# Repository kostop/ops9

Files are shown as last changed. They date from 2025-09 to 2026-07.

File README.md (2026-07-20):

# OPS9 全局定位模块

基于 STM32F103C8 的全局定位模块控制工程。主控通过两路编码器和 IMU 获取运动状态，计算底盘平面位置与航向角，并通过串口向外部控制器发送定位反馈数据。

## 项目内容

| 路径 | 说明 |
| --- | --- |
| `code/` | STM32CubeMX 工程、应用代码、HAL 驱动和 Keil MDK 工程 |
| `code/MDK-ARM/ops9.uvprojx` | Keil uVision 主工程 |
| `pcb/OPS9.epro` | 主板 PCB 工程 |
| `model/` | 机械总装配模型、STL 文件和打印示例 |
| `example/` | 样例底盘的 STM32、PCB、模型与 HMI 工程 |
| `全局定位模块材料清单.xlsx` | 主模块物料清单 |

## 硬件与外设

- MCU：STM32F103C8，外部晶振经 PLL 配置为 72 MHz。
- 两路编码器：TIM1 / PA8、TIM2 / PA0，用于读取两侧轮速和累计脉冲。
- IMU：USART1，115200 bps，PB6 为 TX、PB7 为 RX；使用 DMA 空闲接收。
- 外部通信：USART2，115200 bps，PA2 为 TX、PA3 为 RX；使用中断收发。
- I2C：I2C1，PB8 为 SCL、PB9 为 SDA。
- 状态指示灯：PC13。

## 软件功能

- 读取两路编码器脉冲，计算角速度、轮速和累计里程。
- 接收 IMU 偏航角，处理跨越 `-PI` / `PI` 的航向累计。
- 根据当前行进方向将轮速积分为平面位置 `x`、`y` 和航向 `z`。
- 周期性通过 USART2 上报定位数据；发送帧以 `0x5C` 开头，包含 `x`、`y`、`z` 和 CRC8。
- 接收外部控制命令；收到 `0x22` 时会复位 MCU。

## 编译与下载

1. 安装 Keil MDK-ARM，并添加 STM32F1 设备包。
2. 使用 Keil uVision 打开 `code/MDK-ARM/ops9.uvprojx`。
3. 按实际硬件确认 `code/ops9.ioc` 中的时钟、引脚和串口配置；如使用 STM32CubeMX 重新生成代码，需保留各文件的 `USER CODE` 区域。
4. 在 Keil 中选择 `ops9` 目标，执行 Build。
5. 使用 ST-Link 或兼容 SWD 调试器下载生成的固件。

## 串口使用注意事项

当前工程的 USART1 和 USART2 都按全双工异步串口配置。若硬件改为单线、RS-485 无自动方向控制，或让一条线在收发之间切换，则属于半双工通信，必须重新设计串口收发流程。

> **高风险：半双工场景下，在发送未完成时重新启动接收，或在接收回调中直接发起发送，可能使 HAL 的 `gState` / `RxState` 长期保持 `HAL_UART_STATE_BUSY_*`。后续 `HAL_UART_Transmit_*` 或 `HAL_UART_Receive_*` 会持续返回 `HAL_BUSY`，表现为串口“锁死”。**

- 同一 UART 同一时刻只允许一个收发事务。发送前检查状态或维护独立的软件状态机；不要像当前 `Robot_com_send_data()` 一样无条件高频调用 `HAL_UART_Transmit_IT()` 后又假定已经发送成功。
- 半双工方向应由明确的状态机控制：停止接收 -> 切换为发送方向 -> 启动发送 -> 在 `HAL_UART_TxCpltCallback()` 中确认发送完成 -> 切换为接收方向 -> 重新启动接收。
- 不要在 `HAL_UART_RxCpltCallback()`、`HAL_UARTEx_RxEventCallback()` 等中断回调中使用阻塞式 `HAL_UART_Transmit()`、延时函数或复杂业务逻辑。回调只记录事件、复制数据或投递标志，实际发送放到主循环或任务中处理。
- 必须检查每次 HAL 串口调用的返回值。发生 `HAL_BUSY`、超时、帧错误、噪声错误或溢出错误时，先停止当前事务并清理错误标志，再按统一的恢复流程重新初始化或重新启动接收。
- 若使用 RS-485 收发器，DE/RE 的时序应覆盖整个发送过程，并以发送完成回调为准释放总线；不能仅依据写入发送寄存器就立即切换方向。
- DMA 接收缓冲区在重新启动 `HAL_UARTEx_ReceiveToIdle_DMA()` 前不得被其他上下文修改。正常模式 DMA 完成或空闲事件后，应只重新启动一次，避免中断和主循环并发重复启动。
- 为串口事务设置合理超时和错误计数；连续异常时执行受控恢复。恢复失败后再由看门狗或上层策略复位，避免在中断中无限重试。

推荐的半双工流程如下：

```text
空闲/接收 -> 收到完整请求 -> 停止接收并切换 TX 方向
          -> 启动发送 -> Tx 完成回调 -> 切换 RX 方向 -> 重启接收
```

## 开发约定

- 修改 STM32CubeMX 自动生成文件时，仅在 `USER CODE BEGIN` / `USER CODE END` 区域编写用户代码。
- 业务状态、通信参数较多时使用结构体集中管理，避免分散的大量全局变量。
- 新增嵌入式函数时为函数参数补充简洁的中文注释，并保持中断服务函数短小、可预测。
- 提交前应至少验证：编码器方向、IMU 航向零点、串口帧格式、CRC8 校验和异常恢复流程。

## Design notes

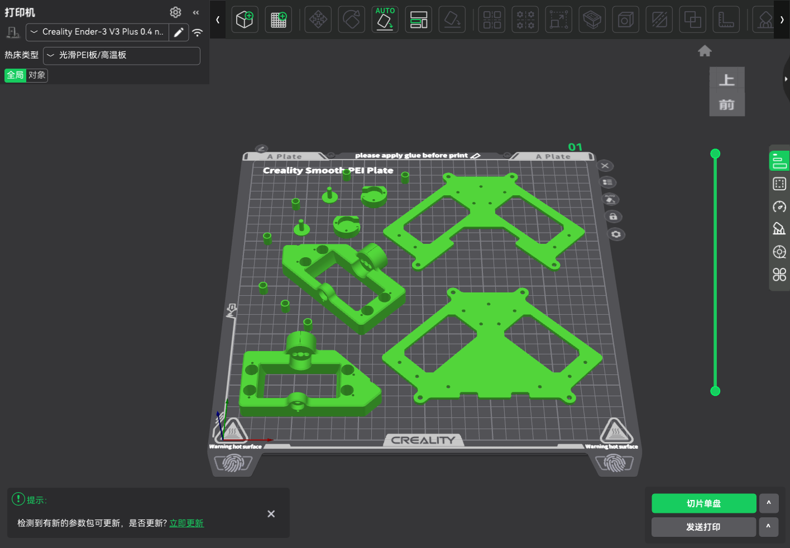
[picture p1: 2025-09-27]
model/打印示例.png

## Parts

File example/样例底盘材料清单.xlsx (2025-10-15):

底盘
序号 | 材料 | 数量 | 单价 | 总价 | 链接（仅作参考） | 备注
 | 底盘电机驱动 | 4 | 49.99 | 199.96 | https://item.taobao.com/item.htm?id=635439412574 | Emm28_V5.0 PLC套餐
 | 电机支架 | 4 | 2.2 | 8.8 | https://item.taobao.com/item.htm?id=580451007567 | 42步进电机支架
 | 底盘电机 | 4 | 19.38 | 77.52 | https://item.taobao.com/item.htm?id=649664531631 | 42电机/高40mm带1000mm杜邦线[D款]
 | OPS9 | 1 |  | 0 |  | OPS9和底盘固定的位置需要添加12mm的打印件垫高（见模型
 | 麦轮 | 1 | 182.8 | 182.8 | https://item.taobao.com/item.htm?id=636447218110 | 75mm（4只麦轮）;5mm;铝套版 这个轮子其实不是很好用，但是便宜，可以自己挑好一点的
 | 板材 | 1 | 100 | 100 | https://item.taobao.com/item.htm?id=738518121036&sku_properties=31309%3A33722 | 见模型
 | 底盘控制板ZET6 | 1 | 110 | 110 | https://detail.tmall.com/item.htm?id=609293737870 | 不焊排针(带SRAM) 可以换其他的控制板，便宜点的
 | 电池 | 1 | 33 | 33 | https://item.taobao.com/item.htm?id=640509882798 | 12V一字型【3000mAh】
 | 电源开关 | 1 | 1.98 | 1.98 | https://detail.tmall.com/item.htm?id=18691413288 | 开孔20mm 全圆实心红色不带灯2档3脚 6A 250V 铜脚 （2个）
 | 降压模块 | 1 | 4.7 | 4.7 | https://item.taobao.com/item.htm?id=522572489248 | 3A超小模块/固定输出5V/D-SUN
 | 铜柱 | 4 | 3.46 | 13.84 | https://detail.tmall.com/item.htm?id=601483145867 | M4*40【5个】
 | GH1.25 | 1 | 0.68 | 0.68 | https://item.taobao.com/item.htm?id=709930896705 | 4P;300MM;杜邦2.54母-1P;GH1.25
 | XT30 | 8 | 1.04 | 8.32 | https://item.taobao.com/item.htm?id=577565809725 | XT30U-F母头 XT30U-M公头 各四个
遥控器
序号 | 材料 | 数量 | 单价 | 总价 | 链接（仅作参考） | 备注
 | 串口屏 | 1 | 103 | 103 | https://item.taobao.com/item.htm?id=583712885361 | 电容触摸模块
 | 无线串口 | 1 | 4.9 | 4.9 | https://item.taobao.com/item.htm?id=630394357164 | L24S[价格];价格
 | 充电模块 | 1 | 2 | 2 | https://item.taobao.com/item.htm?id=962468583902 | 5V/2A充放电模块_Type-C_配USB口
 | 遥控器电池 | 1 | 11.5 | 11.5 | https://detail.tmall.com/item.htm?id=799461424541 | 804050-2000毫安

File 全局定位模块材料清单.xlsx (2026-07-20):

个人方案（并非价格最低，可以根据备注更改方案）
序号 | 材料 | 数量 | 单价 | 总价 | 链接（仅作参考） | 备注
1 | 3D打印耗材PLA | 1 | 71 | 71
2 | 编码器 | 2 | 106 | 212 | https://item.taobao.com/item.htm?id=625215461363 | 1024线 带方向，精度要求不高可以选用256线
3 | 全向轮 | 2 | 30.6 | 61.2 | https://detail.tmall.com/item.htm?from=cart&id=756995416829&skuId=5835440637774&upStreamPrice=3060 | 3mm联轴器
4 | 陀螺仪 | 1 | 337 | 337 | https://item.taobao.com/item.htm?id=587961204951 | 裸片，可以根据需求换更便宜的，但是要注意引脚定义，我这里需求是精度高，所以直接选用这一款了
5 | 铝柱 | 8 | 0.68 | 5.44 | https://item.taobao.com/item.htm?id=775573343427 | M3*35 注意铝柱因为存在公差，最好买同款，但是并非最优的，因为这家铝柱有刷漆，所以需要装上之后去磨合一下 | https://item.taobao.com/item.htm?id=965743472192&xxc=shop&skuId=5438154337255 | 铝柱M3*35亮银本色 群友推荐铝柱
6 | 铝柱 | 4 | 3.8 | 15.2 | https://detail.tmall.com/item.htm?id=719155904600 | M4*35
7 | mcu控制器 | 1 | 9.5 | 9.5 | https://item.taobao.com/item.htm?id=679227834271 | c8t6版型都一样的都可以
8 | 直线轴承 | 8 | 2.8 | 22.4 | https://detail.tmall.com/item.htm?id=598752895908&sku_properties=122276018%3A20213 | LM5UU 5*10*15
9 | 深沟球 | 2 | 0.6 | 1.2 | https://item.taobao.com/item.htm?id=627322360377 | MR104ZZ 4*10*4mm
10 | 推力滚针 | 5 | 0.2 | 1 | https://detail.tmall.com/item.htm?id=717424513282 | 全钢0414+2AS
11 | gh1.25母座 | 1 | 0.1 | 0.1 | https://item.taobao.com/item.htm?id=622151561707 | 立卧都可以看自己需求
12 | 平头螺钉 | 3 | 4 | 12 | https://detail.tmall.com/item.htm?id=624733978863 | M4*20 M3*8 M2*10 M2*6
13 | 弹簧 | 10 | 0.4 | 4 | https://detail.tmall.com/item.htm?id=575363698316
14 | 2.54排母 | 6 | 0.5 | 3 | https://item.taobao.com/item.htm?id=668600526597 | 20P，长了直接剪刀剪了就好了
15 | 2.54排针 | 6 | 0.43 | 2.58 | https://item.taobao.com/item.htm?id=656495617585 | 单排1X40P，长了也是剪了就好了
以下部分可以看需求考虑（直接用串口供电则不需要）
16 | 降压 | 1 | 3.9 | 3.9 | https://item.taobao.com/item.htm?id=522572489248 | 3A超小模块/固定输出5V/D-SUN
17 | xt30 | 1 | 1.55 | 1.55 | https://item.taobao.com/item.htm?from=cart&id=614438530441&skuId=5691715989849&upStreamPrice=155 | XT30PW-M卧式焊板(公头）
 |  |  |  | 760.49

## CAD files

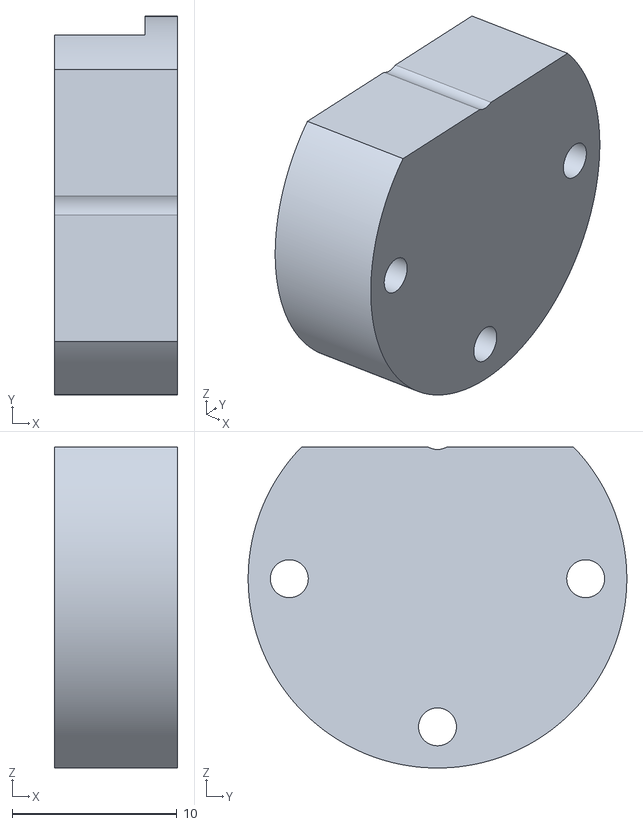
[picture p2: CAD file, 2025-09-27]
model/STL/总装配 - 编码器盖子-3.STL
7.50 x 23.0 x 19.5

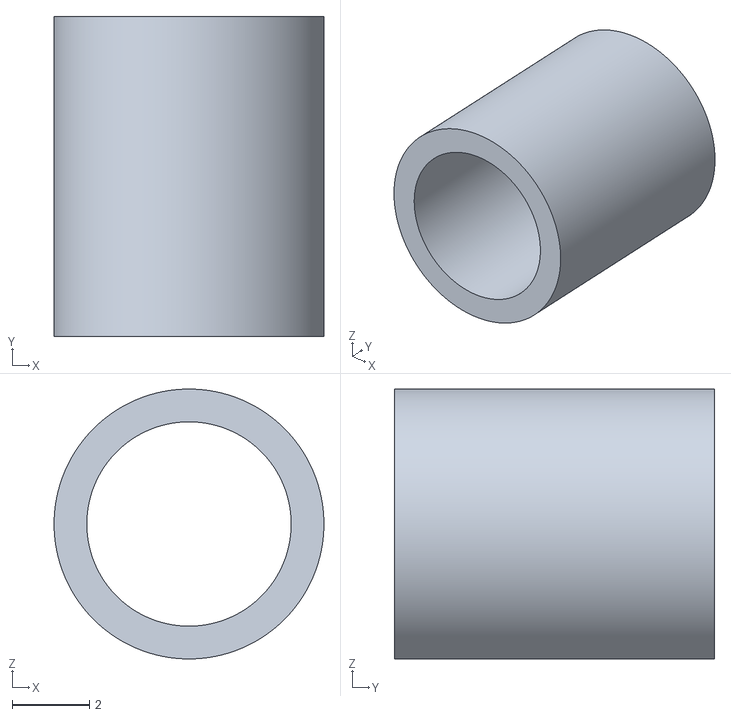
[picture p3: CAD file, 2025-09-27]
model/STL/总装配 - M5 7.5-5.STL
7.00 x 8.30 x 7.00

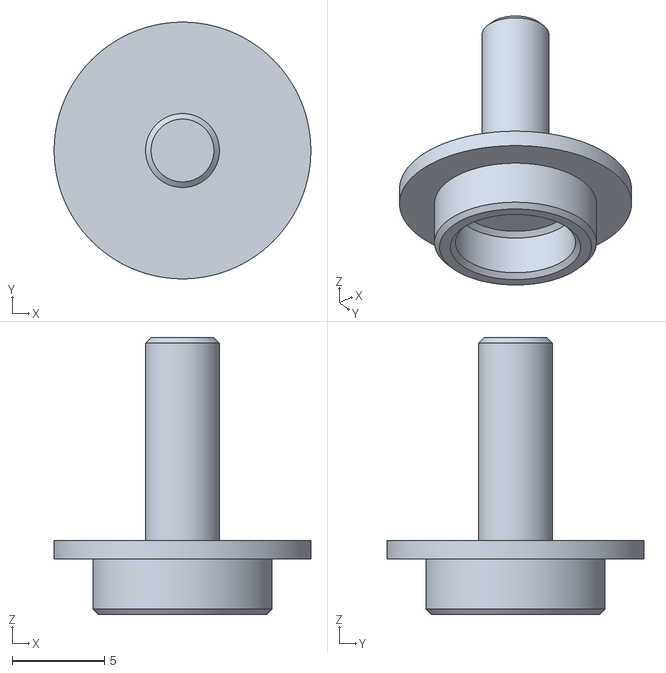
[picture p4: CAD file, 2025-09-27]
model/STL/总装配 - 全向轮轴系固定座-2.STL
13.9 x 13.9 x 15.0

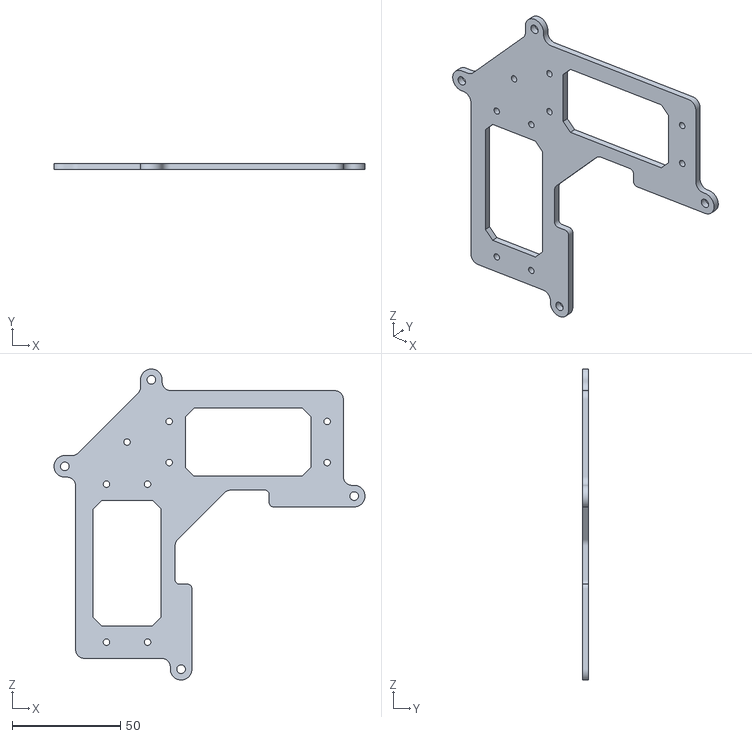
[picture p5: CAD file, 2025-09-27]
model/STL/总装配 - 底板-1.STL
143.7 x 3.00 x 143.7

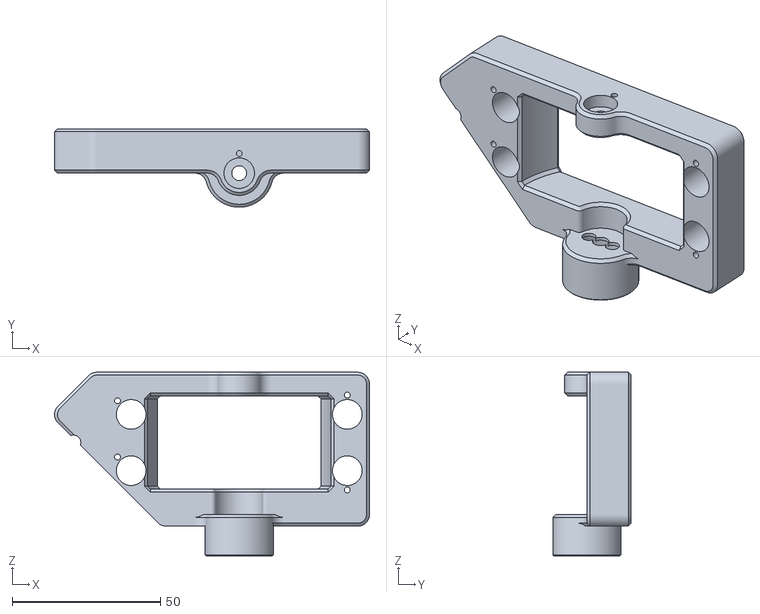
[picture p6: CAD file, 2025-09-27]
model/STL/总装配 - 编码器固定1-1.STL
106.4 x 26.5 x 62.0

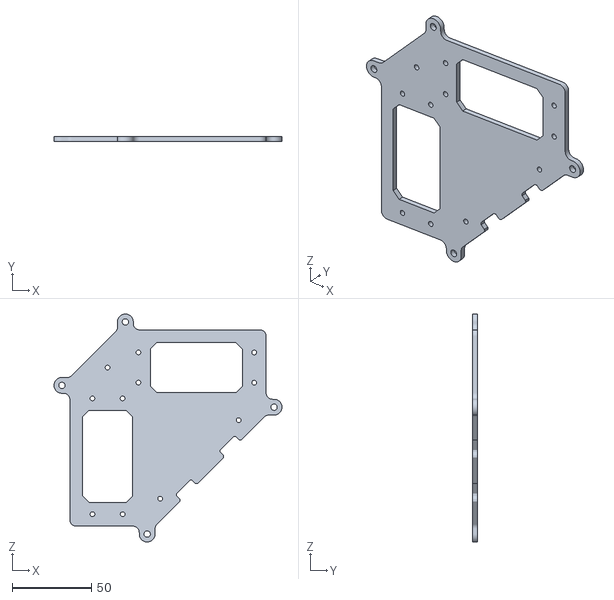
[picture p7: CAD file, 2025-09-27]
model/STL/总装配 - 顶板-1.STL
143.7 x 3.00 x 143.7

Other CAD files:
model/STL/总装配 - M5 7.5-3.STL
model/STL/总装配 - M5 7.5-6.STL
model/STL/总装配 - 全向轮轴系固定座-1.STL
model/STL/总装配 - M5 7.5-7.STL
model/STL/总装配 - M5 7.5-4.STL
model/STL/总装配 - M5 7.5-1.STL
model/STL/总装配 - 编码器固定2-3.STL
model/STL/总装配 - 编码器盖子2-1.STL
model/STL/总装配 - M5 7.5-2.STL

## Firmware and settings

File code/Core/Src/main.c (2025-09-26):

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
/* Includes ------------------------------------------------------------------*/
#include "main.h"
#include "dma.h"
#include "i2c.h"
#include "tim.h"
#include "usart.h"
#include "gpio.h"

/* USER CODE BEGIN Includes */
#include "encoder.h"
#include "delay.h"
#include "imu.h"
#include "ops9_control.h"
#include "robot_com.h"
/* USER CODE END Includes */

/* USER CODE BEGIN PD */
#define LED_DELAY		1000		//ms
#define TASK_TIME_OUT	1
/* USER CODE END PD */


/* USER CODE BEGIN PV */
uint16_t led_delay;
uint8_t get_yaw_state;
uint8_t ops9_dirt;
/* USER CODE END PV */

void SystemClock_Config(void);
/* USER CODE BEGIN PFP */
static void LED_task(uint32_t delay);
/* USER CODE END PFP */

/**
  * @brief  The application entry point.
  * @retval int
  */
int main(void)
{

  /* MCU Configuration--------------------------------------------------------*/

  /* Reset of all peripherals, Initializes the Flash interface and the Systick. */
  HAL_Init();

  /* Configure the system clock */
  SystemClock_Config();

  /* Initialize all configured peripherals */
  MX_GPIO_Init();
  MX_DMA_Init();
  MX_I2C1_Init();
  MX_TIM1_Init();
  MX_TIM2_Init();
  MX_USART1_UART_Init();
  MX_USART2_UART_Init();
  MX_TIM3_Init();
  /* USER CODE BEGIN 2 */
  delay_init();
  Encoder_init();
  IMU_init();
  Robot_com_init();
  Control_init(TASK_TIME_OUT);
  /* USER CODE END 2 */

  /* Infinite loop */
  /* USER CODE BEGIN WHILE */
  while (1)
  {
	LED_task(LED_DELAY);
	Encoder_task();
	Robot_com_send_data();
	Control_task(ops9_dirt);
	IMU_check_task();
	delay_ms(TASK_TIME_OUT);
	switch(get_ops_cmd_data())
	{
		case 0x22:
			NVIC_SystemReset();
			break;
		default:
			ops9_dirt = get_ops_cmd_data()-0x30;
			
	}
    /* USER CODE END WHILE */

    /* USER CODE BEGIN 3 */
  }
  /* USER CODE END 3 */
}

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
/* USER CODE BEGIN 4 */
void LED_task(uint32_t delay)
{
	static uint32_t led_delay =0;
	led_delay ++;
	if(led_delay >= delay)
	{
		HAL_GPIO_TogglePin(GPIOC, GPIO_PIN_13);
		led_delay =0;
	}
}

void HAL_UART_RxCpltCallback(UART_HandleTypeDef *huart)
{
	if(huart->Instance == USART2)
	{
		Robot_com_call_back();
	}
}

/* USER CODE END 4 */
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


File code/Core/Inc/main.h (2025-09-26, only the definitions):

#define LED0_Pin GPIO_PIN_13
#define LED0_GPIO_Port GPIOC
#define STEP2_Pin GPIO_PIN_0
#define STEP2_GPIO_Port GPIOA
#define STEP_ZERO1_Pin GPIO_PIN_14
#define STEP_ZERO1_GPIO_Port GPIOB
#define STEP_ZERO2_Pin GPIO_PIN_15
#define STEP_ZERO2_GPIO_Port GPIOB
#define STEP1_Pin GPIO_PIN_8
#define STEP1_GPIO_Port GPIOA
#define DIRT1_Pin GPIO_PIN_10
#define DIRT1_GPIO_Port GPIOA
#define DIRT1A11_Pin GPIO_PIN_11
#define DIRT1A11_GPIO_Port GPIOA
#define ANGLE_ZERO_Pin GPIO_PIN_5
#define ANGLE_ZERO_GPIO_Port GPIOB
#define USART_IMU_TX_Pin GPIO_PIN_6
#define USART_IMU_TX_GPIO_Port GPIOB
#define USART_IMU_RX_Pin GPIO_PIN_7
#define USART_IMU_RX_GPIO_Port GPIOB
#define IMU_SCL_Pin GPIO_PIN_8
#define IMU_SCL_GPIO_Port GPIOB
#define IMU_SDA_Pin GPIO_PIN_9
#define IMU_SDA_GPIO_Port GPIOB

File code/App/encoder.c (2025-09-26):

#include "encoder.h"
#include "tim.h"

#define ENCODER_PULSE			1024.0f
#define ENCODER_TASK_TIME_OUT	0.001f		//s


encoder_para_t encoder_para[2];

void Encoder_init(void)
{
	HAL_TIM_Encoder_Start(&htim1, TIM_CHANNEL_1);
	HAL_TIM_Encoder_Start(&htim2, TIM_CHANNEL_1);
}

void Encoder_task(void)
{
	encoder_para[0].dirt = HAL_GPIO_ReadPin(GPIOA, GPIO_PIN_10)*2-1;
	encoder_para[0].count = __HAL_TIM_GetCounter(&htim1)*encoder_para[0].dirt;
	__HAL_TIM_SetCounter(&htim1, 0);
	encoder_para[0].rate = (float)encoder_para[0].count/ENCODER_PULSE/ENCODER_TASK_TIME_OUT*2*PI;
	encoder_para[0].total_count += encoder_para[0].count;
	
	encoder_para[1].dirt = HAL_GPIO_ReadPin(GPIOA, GPIO_PIN_11)*2-1;
	encoder_para[1].count = __HAL_TIM_GetCounter(&htim2)*encoder_para[1].dirt;
	__HAL_TIM_SetCounter(&htim2, 0);
	encoder_para[1].rate = (float)encoder_para[1].count/ENCODER_PULSE/ENCODER_TASK_TIME_OUT*2*PI;
	encoder_para[1].total_count += encoder_para[1].count;
}

const encoder_para_t *get_encoder_para_point(uint8_t num)
{
	return &encoder_para[num];
}

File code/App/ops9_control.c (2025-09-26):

#include "ops9_control.h"
#include <math.h>

#define WHEEL_RADIUS			0.029f		//m
uint8_t ops9_direction = 0;

float Control_task_time_out;

control_para_t control_para;

static void feed_back(control_para_t *feed_back_point);
static void control_loop(control_para_t *control_loop_point);

float yaw_add_count(float yaw)
{
	static float yaw_last, yaw_add;
	float yaw_result;
	if(yaw - yaw_last < -PI)
		yaw_add += 2*PI;
	else if(yaw - yaw_last > PI)
		yaw_add -= 2*PI;
	
	yaw_last = yaw;
	yaw_result = yaw + yaw_add;
	return yaw_result;
}

void Control_init(uint16_t Task_time_out)
{
	ops9_direction = 2;
	for(int i=0; i<2; i++)
		control_para.control_encoder_point[i] = get_encoder_para_point(i);
	control_para.control_imu_point = get_imu_para_point();
	Control_task_time_out = 0.001f;
}

void Control_task(uint8_t dirt)
{
//	ops9_direction = dirt;
	feed_back(&control_para);
	control_loop(&control_para);
}

static void feed_back(control_para_t *feed_back_point)
{
	for(int i=0; i<2; i++)
	{
		feed_back_point->wheel_para[i].angle = (float)feed_back_point->control_encoder_point[i]->total_count/1024*2*PI;
		feed_back_point->wheel_para[i].len = feed_back_point->wheel_para[i].angle*WHEEL_RADIUS;
		feed_back_point->wheel_para[i].rate = feed_back_point->control_encoder_point[i]->rate;
		feed_back_point->wheel_para[i].speed = feed_back_point->wheel_para[i].rate*WHEEL_RADIUS;
	}

	feed_back_point->chassis_pos.z = yaw_add_count(feed_back_point->control_imu_point->yaw);
}

static void control_loop(control_para_t *control_loop_point)
{
	switch(ops9_direction)
	{
		case 0:
			control_loop_point->chassis_line.y = control_loop_point->wheel_para[0].speed*Control_task_time_out;
			control_loop_point->chassis_line.x = -control_loop_point->wheel_para[1].speed*Control_task_time_out;
			break;
		case 1:
			control_loop_point->chassis_line.x = control_loop_point->wheel_para[0].speed*Control_task_time_out;
			control_loop_point->chassis_line.y = control_loop_point->wheel_para[1].speed*Control_task_time_out;
			break;
		case 2:
			control_loop_point->chassis_line.y = -control_loop_point->wheel_para[0].speed*Control_task_time_out;
			control_loop_point->chassis_line.x = control_loop_point->wheel_para[1].speed*Control_task_time_out;
			break;
		case 3:
			control_loop_point->chassis_line.x = -control_loop_point->wheel_para[0].speed*Control_task_time_out;
			control_loop_point->chassis_line.y = -control_loop_point->wheel_para[1].speed*Control_task_time_out;
			break;
	}
	float sin_angle = sin(control_loop_point->chassis_pos.z);
	float cos_angle = cos(control_loop_point->chassis_pos.z);
	
	
	control_loop_point->chassis_pos.x += control_loop_point->chassis_line.x * cos_angle - control_loop_point->chassis_line.y * sin_angle;
	control_loop_point->chassis_pos.y += control_loop_point->chassis_line.x * sin_angle + control_loop_point->chassis_line.y * cos_angle;
}


const control_para_t *get_control_para_point(void)
{
	return &control_para;
}

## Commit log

2025-09-27 材料清单
    [全局定位模块材料清单.xlsx]
2025-10-07 更正清单
    [全局定位模块材料清单.xlsx]
2025-10-07 上传底盘案例
    [样例底盘材料清单.xlsx]
2025-10-15 上传底盘、遥控器材料清单
    [样例底盘材料清单.xlsx]
2026-07-20 新增材料清单项目
    [全局定位模块材料清单.xlsx]

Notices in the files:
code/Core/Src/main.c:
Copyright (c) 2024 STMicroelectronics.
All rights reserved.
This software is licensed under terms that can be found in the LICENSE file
